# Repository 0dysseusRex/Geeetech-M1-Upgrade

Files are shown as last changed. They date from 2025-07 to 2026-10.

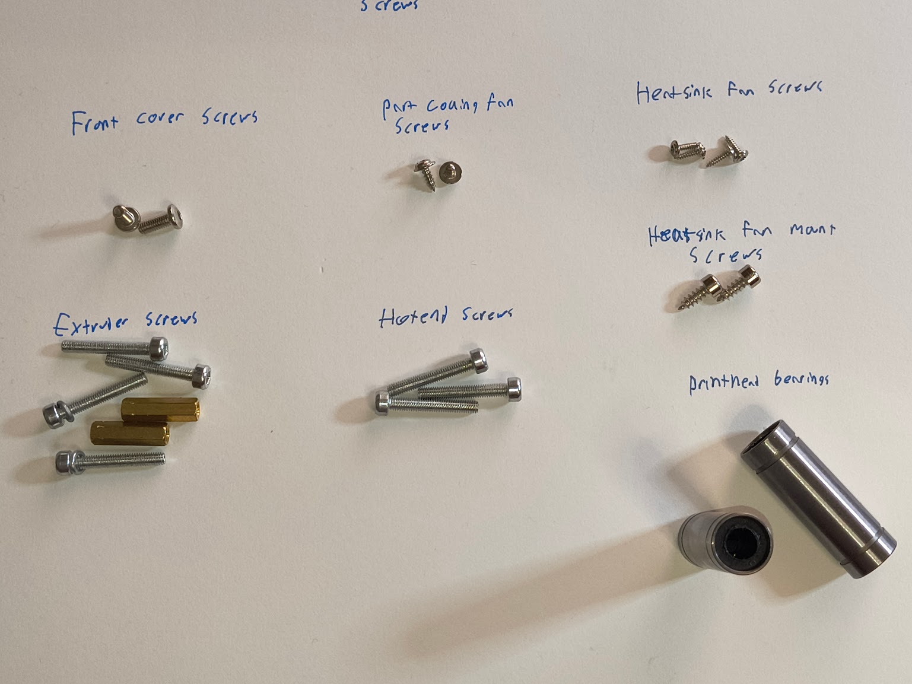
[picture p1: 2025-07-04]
Photos/Printhead Screws.jpg

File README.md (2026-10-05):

# 🛠️ Geeetech M1 Klipperization & Upgrade Project

Welcome to the build guide for transforming your humble Geeetech M1 into a lean, mean, Klipper-powered printing machine. This README outlines the upgrades, installation steps, and configuration notes for the project.

> 💡 Help me fund a 3D scanner so I can stop squeezing magic out of Polycam and a Razor phone.  
> 

---

<details>
<summary>📊 <strong>Project Completion Tracker</strong> — 40% Overall (Weighted by Major Milestones) — Click to expand</summary>

> **Note:** Project completion is calculated by assigning weights to major milestones as follows:
> - Printhead Re-design: 30%
> - Gantry Re-design: 30%
> - Electronics Mount: 20%
> - Software: 20%
> Weighted progress is shown below. All other tasks are tracked for transparency but do not affect the overall percentage.

### 🔧 Printhead Re-design — 90% (27% of total)
`█████████░`  
**✅ Completed:**  
- A1 Mini Hotend ✔️  
- Probe mounting location ✔️  
- Microprobe mount ✔️  
- Fan mounts ✔️  
- Cable guides ✔️  

**📝 To Do:**  
- Redesign bottom screw mounts to point forwards ❌  

---

### 🏗️ Gantry Re-design — 100% (30% of total)
`██████████`  
- Universal screw holes for custom MCU mounts ✔️  

---

### ⚙️ Electronics Mount — 60% (12% of total)
`██████░░░░`  
**✅ Completed:**  
- SKR Pico Mount ✔️  
**📝 To Do:**  
- Fly Lite 2.1 mount ❌  
- Knomi Mount ❌  
- E-stop Mount ❌  

The finished `STL Files/Electronics Mount/Pi Mount.stl` fits the previous Raspberry Pi Zero 2W host. It is not a verified Mellow Fly Lite 2.1 mount, so that STL is unchanged. The 60% figure above still counts that Pi mount.  

---

### 💻 Software — 0% (0% of total)
`░░░░░░░░░░`  
- Flash the Fly-bian 1.0 Simple-AF image on the Fly Lite 2.1 ❌  
- Draft `printer.cfg` written, not tested on the machine ❌  
- Run the Simple-AF install command in the installation section ❌  
- Test functionality ❌  

---

### 🔌 PSU Mount — 0%
`░░░░░░░░░░`  
- Not yet started ❌  

---

### 🧪 Testing — 0%
`░░░░░░░░░░`  
- Initial printer function tests ❌  
- PID tuning ❌  
- Input shaper graphs ❌  
- First test prints ❌  
- Speed tests ❌  
- Dial-in settings ❌  

---

### 🎬 Video Editing — 0%
`░░░░░░░░░░`  
- Not yet started ❌  

---

### 🌐 Publish & Go Live — 0%
`░░░░░░░░░░`  
- Awaiting completion ❌  

</details>

---

## 🧰 Project Overview

This upgrade journey includes:

- **Mainboard**: BTT SKR Pico (Klipper MCU)
- **Controller**: [Mellow Fly-Pi-lite2.1](https://mellow.klipper.cn/en/docs/ProductDoc/SBC/fly-lite/lite2.1/) (Fly Lite 2.1), the Klipper host
- **Host image**: [Fly-bian 1.0 Simple-AF](https://github.com/0dysseusRex/fly-bian/releases/tag/v1.0) — `Fly-bian-1.0_Fly-Lite-2.1_Simple-AF-0d21afe.img.xz`. This is unofficial Armbian/Debian from [fly-bian](https://github.com/0dysseusRex/fly-bian), not Mellow FlyOS
- **Power Supply**: Internal 100W unit for compact, clean power delivery
- **Custom Printhead Assembly**:
  - A1 Mini hotend for improved thermal performance  
  - Creality K1 extruder for smoother filament feed  
  - Microprobe sensor for reliable bed leveling
- **Streaming Camera**: Live monitoring via a USB camera on the Fly Lite

---

## 📦 Hardware List

| Component | Model/Description |
|---|---|
| Mainboard | BTT SKR Pico (Klipper MCU) |
| Controller | Mellow Fly-Pi-lite2.1 (Fly Lite 2.1) |
| Host image | Fly-bian 1.0 Simple-AF (`Fly-bian-1.0_Fly-Lite-2.1_Simple-AF-0d21afe.img.xz`) |
| Power Supply | Internal 100W |
| Hotend | A1 Mini |
| Extruder | Creality K1 |
| Bed Leveling | Microprobe sensor |
| Streaming Camera | USB (Fly Lite USB-A; no CSI connector on this host) |

---

## 🛠️ Installation Highlights

- **Controller (Fly Lite 2.1)**  
  - Flash only the Simple-AF card: [Fly-bian-1.0_Fly-Lite-2.1_Simple-AF-0d21afe.img.xz](https://github.com/0dysseusRex/fly-bian/releases/download/v1.0/Fly-bian-1.0_Fly-Lite-2.1_Simple-AF-0d21afe.img.xz) (SHA256 `3523ba04239469a7654b9d3b5ce8d07d9bf0d138a92ea3c833cd38d0f7c9e470`). Do not flash the Base or KIAUH image, FlyOS, or Raspberry Pi OS
  - Mellow specifies a MicroSD of 16–128 GB, speed class C10 or higher. The board has no eMMC
  - Before the first power-on, edit `fly-start.txt` on the `FLY-SETUP` volume (2.4 GHz Wi-Fi, locale, root password, sudo user). Steps: [Fly-bian Simple-AF how-to](https://github.com/0dysseusRex/fly-bian/blob/main/docs/howto-simpleaf.md)
  - Power the host from its own 5 V supply. Mellow says the Fly-Pi-lite2.1 must not be powered from the printer mainboard
  - Fit the IPEX antenna. Onboard Wi-Fi is 2.4 GHz only
  - After SSH login, `~/pellcorp` is already on the card. [Simple-AF for RPi](https://pellcorp.github.io/creality-wiki/rpi/) accepts a custom printer file as `--printer` (a GitHub file URL or a local path) and the probe as `--probe`. This machine is not one of the predefined printers, so there is no `--mount`. The draft [`printer.cfg`](printer.cfg) is that file. Run:

    ```
    ~/pellcorp/installer.sh --install --printer https://github.com/0dysseusRex/Geeetech-M1-Upgrade/blob/main/printer.cfg --probe microprobe
    ```

    The same line can be `INSTALL_CMD=` in `fly-start.txt` on the `FLY-SETUP` volume before the first boot. That is the hook in the [Fly-bian Simple-AF how-to](https://github.com/0dysseusRex/fly-bian/blob/main/docs/howto-simpleaf.md). The installer rewrites the GitHub URL to the raw file. `printer.cfg` is still a draft
  - The SKR Pico stays the MCU and still connects over USB. No Fly Lite GPIO pinout is added here
  - Wire power and comms with care—use ferrules for safety and reliability

- **Printhead Upgrade**  
  - Swap stock hotend for A1 Mini  
  - Mount Creality K1 extruder and calibrate steps/mm in Klipper  
  - Install Microprobe and configure mesh leveling

- **Power Integration**  
  - Mount internal 100W PSU  
  - Ensure tidy cable management and proper airflow

- **Camera Streaming**  
  - Connect a USB camera to a Fly Lite USB-A port. A CSI camera connector is not listed on the Fly-Pi-lite2.1
  - After Crowsnest is installed, `fly-crowsnest-add-cams` adds the camera. Fluidd and Mainsail are the web UIs on this image

---

## 🧠 Configuration Notes

- [`printer.cfg`](printer.cfg) is the Simple-AF `--printer` file for the SKR Pico MCU. Probe and mesh values are in its `-- microprobe.cfg` section so the installer keeps the SKR Pico probe pins. Simple-AF's own `START_PRINT` homes with `G28` on the mechanical endstops, then meshes. The Fly Lite 2.1 is the host. Its only documented Klipper GPIO is the KPPM pin, and this config does not load that pin. [`adxl345.cfg`](adxl345.cfg) is not part of that install; include it only while the USB accelerometer is plugged in
- Run PID tuning for hotend and bed  
- Enable Input Shaping with accelerometer (optional but recommended)  
- View the camera stream in Fluidd or Mainsail on the Fly Lite

---

## ✨ Acknowledgments

Big thanks to the Klipper community, BTT engineers, Pellcorp ([Simple AF](https://pellcorp.github.io/creality-wiki/)), Mellow for the [Fly-Pi-lite2.1](https://mellow.klipper.cn/en/docs/ProductDoc/SBC/fly-lite/lite2.1/), the [Fly-bian](https://github.com/0dysseusRex/fly-bian) image, and [adamrodgers/geeetech-m1s-klipper](https://github.com/adamrodgers/geeetech-m1s-klipper) for the stock M1S X/Y/Z motor steps, travel, homing direction, and cartesian kinematics in `printer.cfg`. That project keeps the original M1S board, so only those motion numbers were used here. And thanks to all the DIYers who turn retro machines into futuristic wonders.

---

> 🧠 Print smarter, not harder.  
> 🤖 Yes, this README was AI-generated—but only as a launchpad. BOM coming soon.

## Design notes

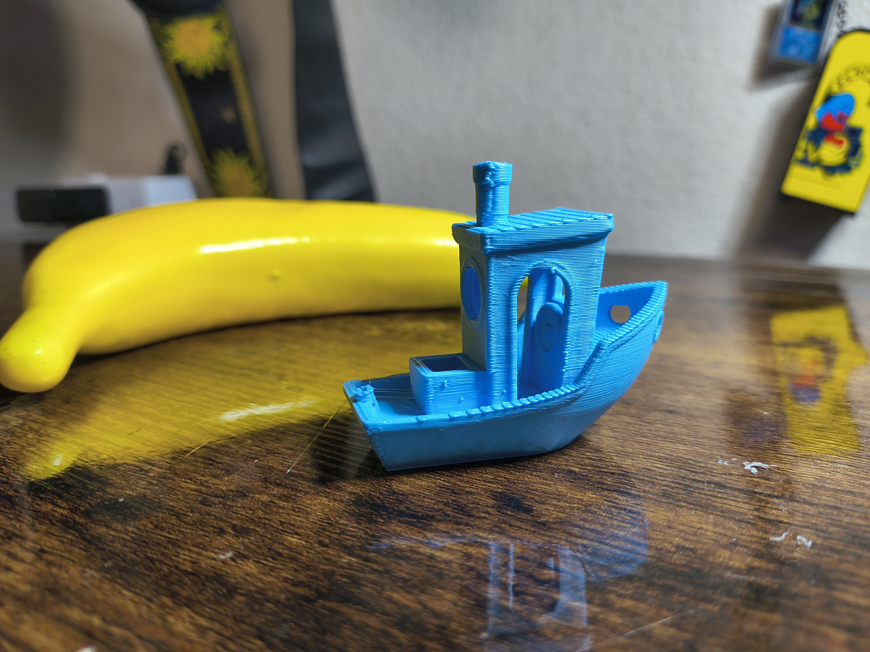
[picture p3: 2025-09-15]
Photos/IMG_20250629_211448033_HDR.jpg

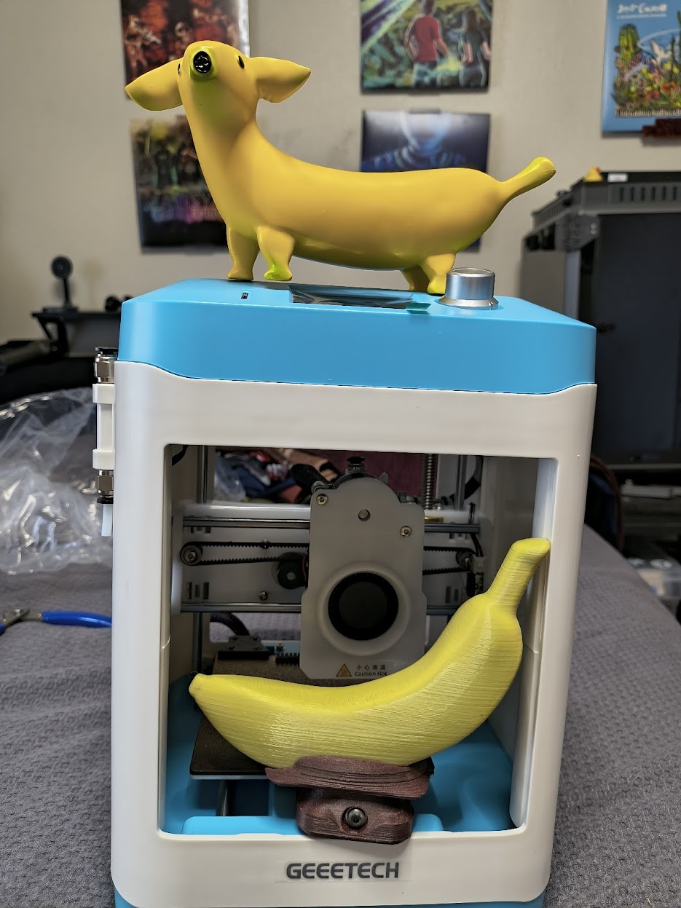
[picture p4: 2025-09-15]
Photos/IMG_20250625_182029436_HDR.jpg

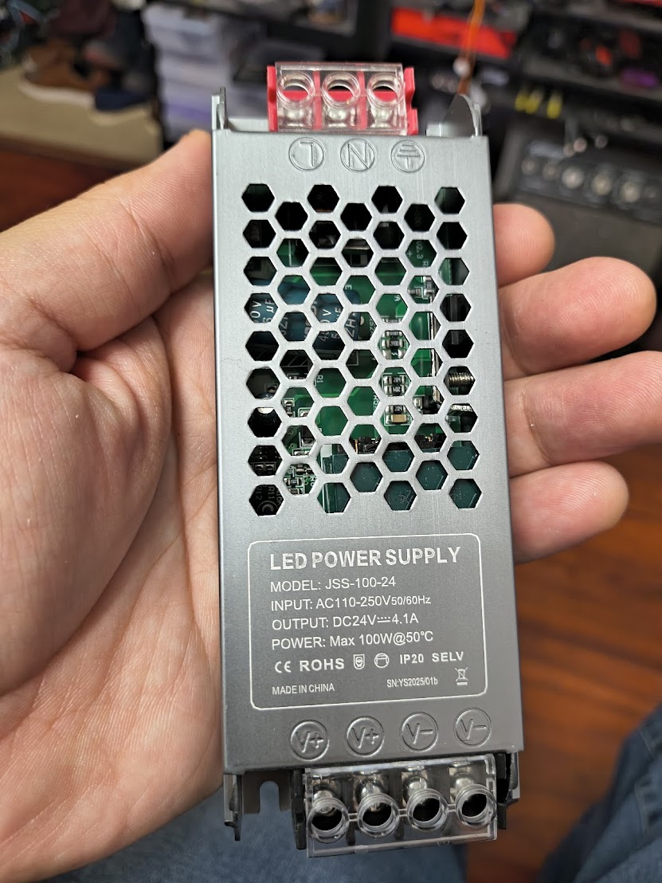
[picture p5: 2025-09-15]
Photos/IMG_20250629_103606269_HDR.jpg

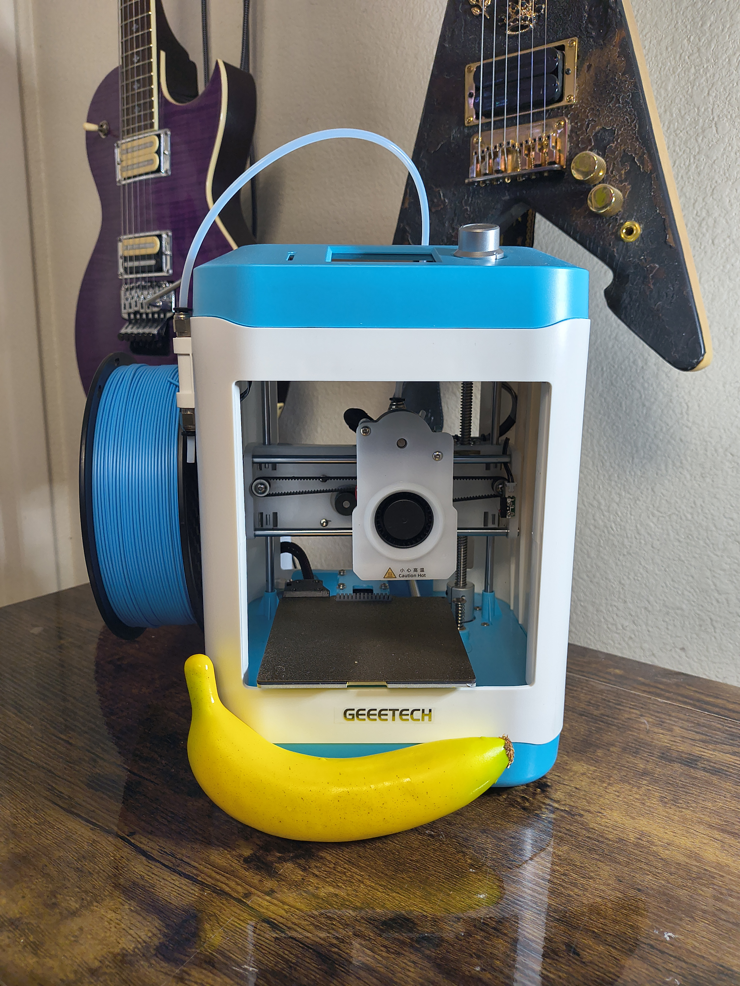
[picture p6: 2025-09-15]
Photos/IMG_20250629_200729336_HDR.jpg

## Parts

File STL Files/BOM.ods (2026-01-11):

Printhead BOM
# | Item | Cost | Link
9 | M3 Voron Heat Set Insert | $9.99 | https://www.amazon.com/dp/B0CDH36ZMX
2 | M2.5 Heat Set Insert | $8.99 | https://www.amazon.com/dp/B0CS6YVJYD
2 | 8X2mm magnets | $6.99 | https://www.amazon.com/dp/B09TVXL3DZ
2 | M4x20 Socket Head Screws | $8.99 | https://www.amazon.com/dp/B0DCVVSGW2

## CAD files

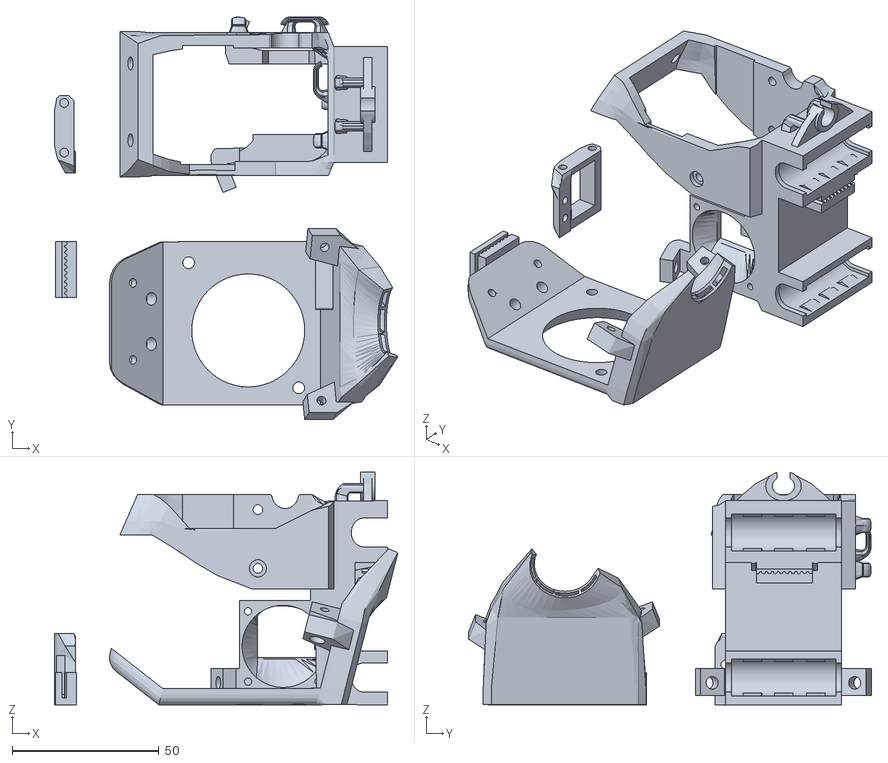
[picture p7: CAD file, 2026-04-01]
STL Files/Printhead/Full Toolhead.stl
117.1 x 137.4 x 79.3

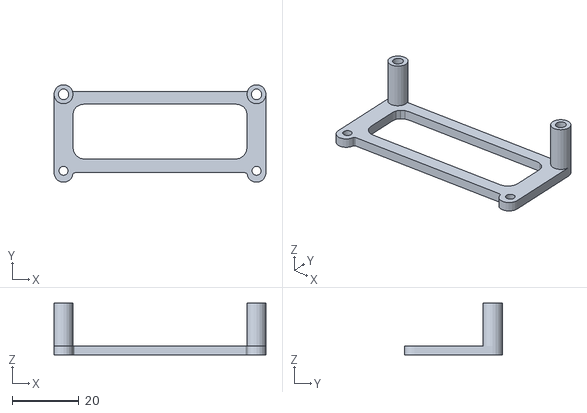
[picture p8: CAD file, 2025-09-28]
STL Files/Electronics Mount/Pi Mount.stl
63.7 x 29.3 x 15.6

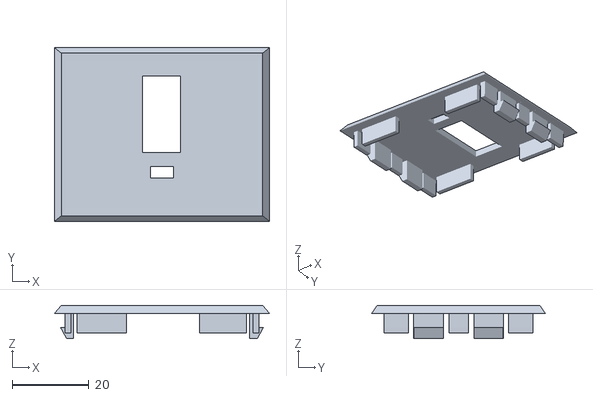
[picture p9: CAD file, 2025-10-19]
STL Files/Knomi/Knomi Mount Base.stl
56.2 x 45.4 x 8.70

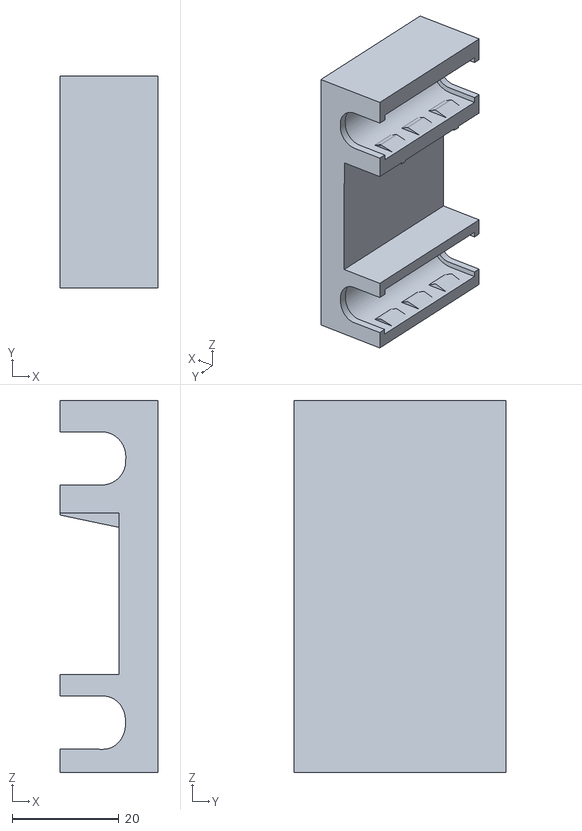
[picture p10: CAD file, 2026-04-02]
STL Files/Printhead/Universal Carriage.stl
18.4 x 39.6 x 69.6

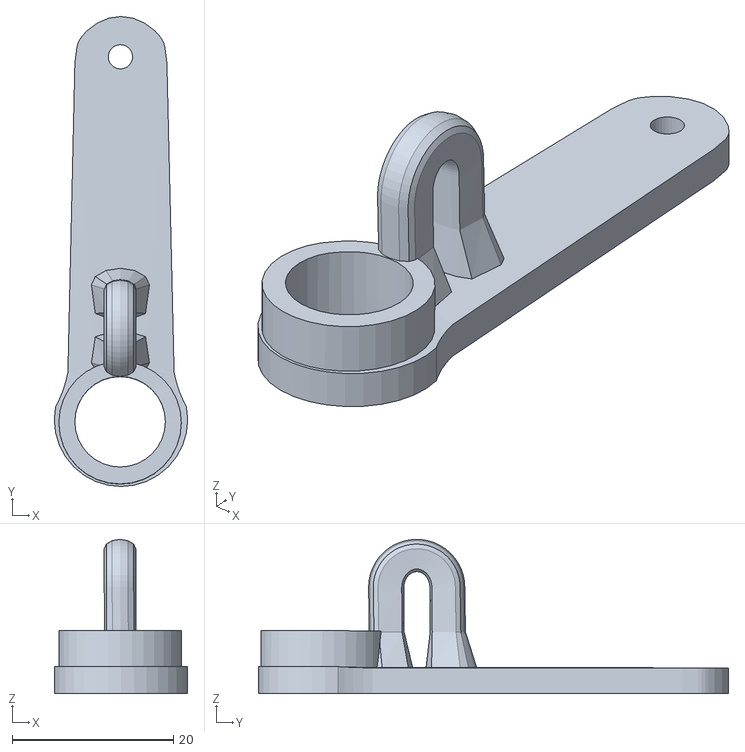
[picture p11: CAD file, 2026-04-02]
STL Files/X Gantry/Cable Guide.stl
16.5 x 58.2 x 19.1

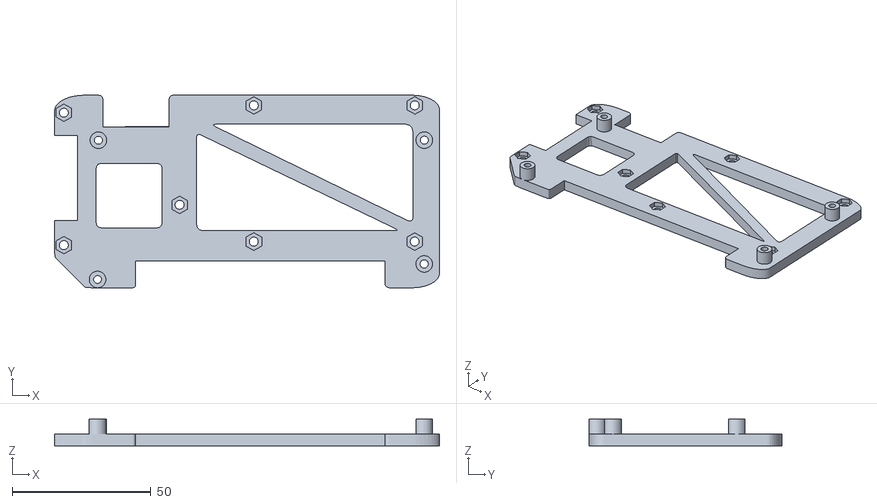
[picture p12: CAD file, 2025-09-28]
STL Files/Electronics Mount/Electronics Mount.stl
138.7 x 69.4 x 9.72

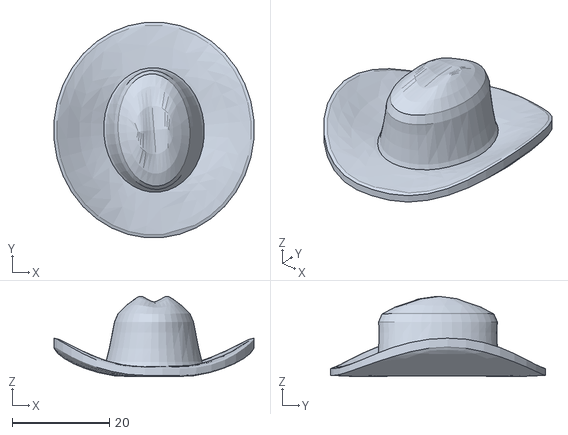
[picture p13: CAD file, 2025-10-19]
STL Files/Knomi/Cowboy Hat.stl
41.2 x 44.3 x 16.5

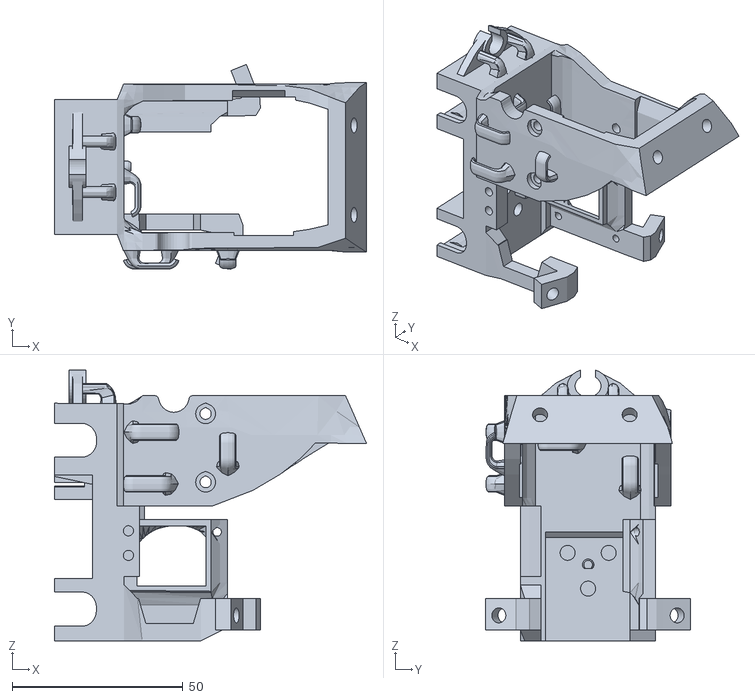
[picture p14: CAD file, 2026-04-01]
STL Files/Printhead/Toolhead.stl
91.3 x 60.0 x 79.3

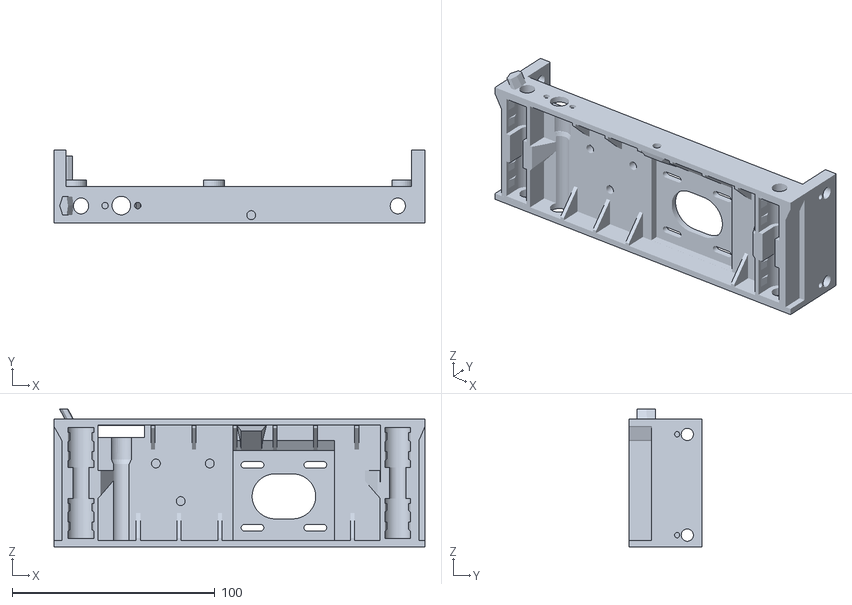
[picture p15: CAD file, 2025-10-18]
STL Files/X Gantry/Gantry.stl
183.0 x 36.0 x 68.0

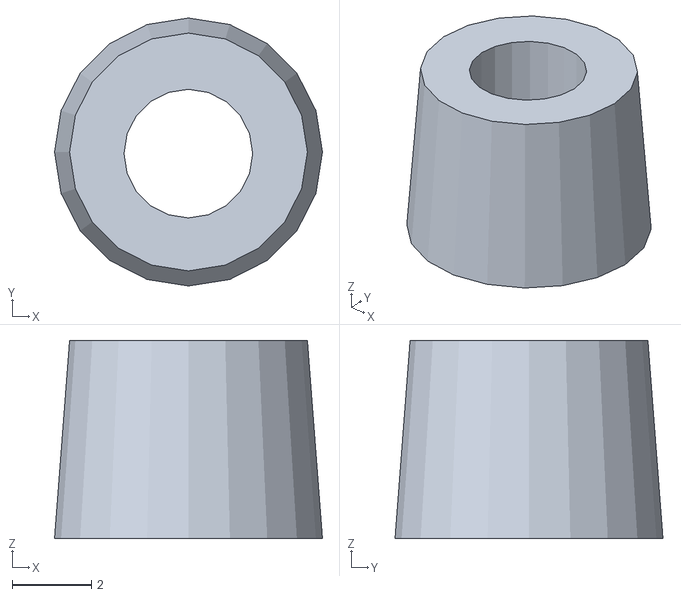
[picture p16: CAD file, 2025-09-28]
STL Files/Electronics Mount/Spacer.stl
6.76 x 6.76 x 5.00

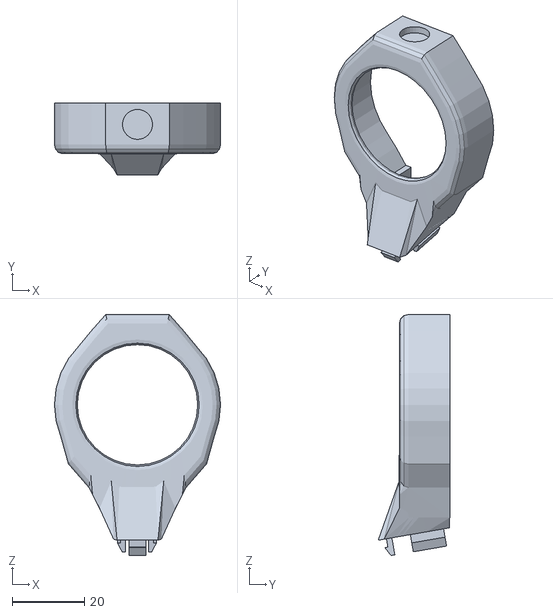
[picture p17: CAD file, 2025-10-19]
STL Files/Knomi/Knomi Case.stl
46.0 x 19.8 x 66.7

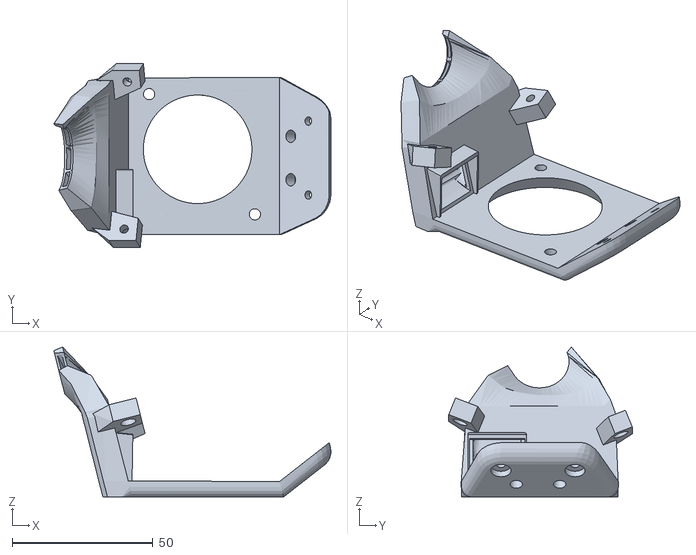
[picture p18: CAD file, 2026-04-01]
STL Files/Printhead/Cover Test.stl
98.3 x 65.1 x 53.2

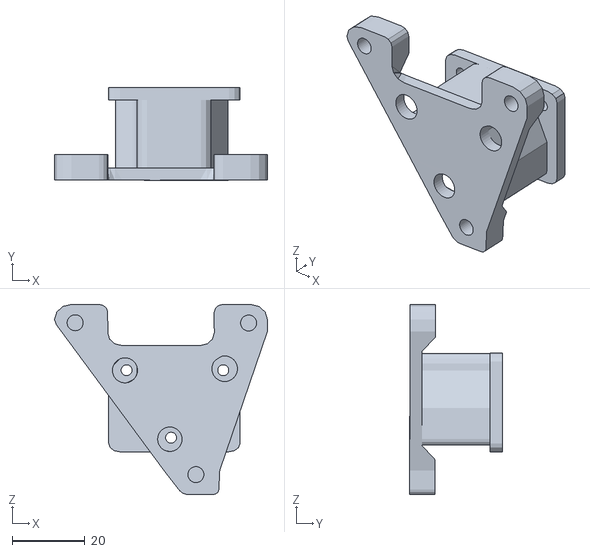
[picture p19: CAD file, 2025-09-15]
STL Files/X Gantry/MCU Mount.stl
58.6 x 25.5 x 52.3

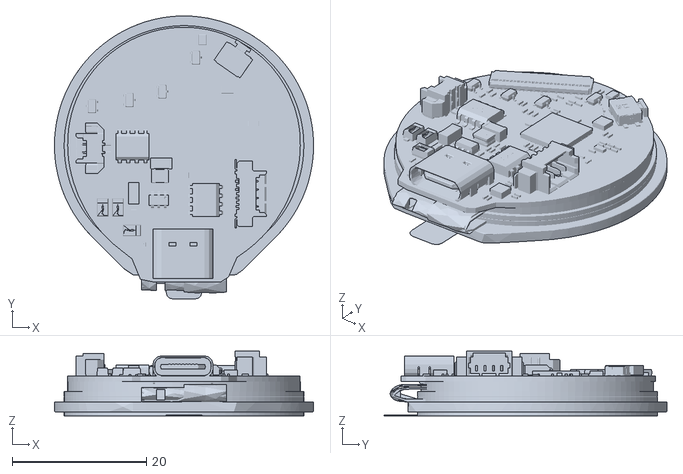
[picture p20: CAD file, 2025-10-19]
STL Files/Knomi/KNOMI 2 Mockup.stl
38.5 x 42.1 x 9.63

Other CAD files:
STL Files/Knomi/Knomi Lid.stl
STL Files/Printhead/Belt Clip.stl
STL Files/Printhead/Microprobe Mount.stl

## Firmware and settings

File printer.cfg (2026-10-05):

# Geeetech M1 — Simple-AF printer definition. Not calibrated. Do not heat
# until the DRAFT sensor types below are replaced with the real ones.
#
# Host: Mellow Fly-Pi-lite2.1 (Fly Lite 2.1) on Fly-bian Simple-AF.
# The Lite is a Klipper host, not a stepper board. Mellow documents one
# host GPIO for Klipper, and only for a KPPM module:
#   host:gpiochip1/gpio8
# https://mellow.klipper.cn/en/docs/ProductDoc/SBC/fly-lite/lite2.1/advanced/kppm/
# This printer config does not load that pin. Do not copy a Fly-Pi 40-pin
# map onto the Lite; Mellow does not publish one for this board.
# https://github.com/0dysseusRex/fly-bian/blob/main/docs/klipper-pins-and-macros.md
#
# Motion MCU: BTT SKR Pico, still the mainboard in this repo. Pin names
# below are the SKR Pico connectors from Klipper's generic config:
# https://github.com/Klipper3d/klipper/blob/master/config/generic-bigtreetech-skr-pico-v1.0.cfg
# Compile that MCU for the RP2040 with USB. "make flash" does not work;
# copy out/klipper.uf2 to the board in boot mode.
#
# Toolhead in this repo: A1 Mini hotend, Creality K1 extruder, BTT
# Microprobe, fan mounts. Motors, endstops, and the first home are the
# original M1. The Microprobe is not the homing endstop.
#
# X/Y/Z rotation distances, travel, and homing direction are from the stock
# M1S Marlin dump (M92/M201/M203/M211/M119). The M1S is the M1 plus Wi-Fi;
# the mechanics match. Source:
# https://github.com/adamrodgers/geeetech-m1s-klipper
# Their MCU pins are for the stock APM32 board and are not used here.
#
# Advertised volume is 100 x 110 x 100 mm. Stock M211 travel is
# X 0..115, Y 0..114, Z 0..95. Nozzle max 230 C, bed max 60 C.
#
# Simple-AF wants one file. Lines that start with "-- name.cfg" are
# sections it copies into that file. It rejects [include] and SAVE_CONFIG.
# https://pellcorp.github.io/creality-wiki/rpi_printer_definitions/
# Comment lines are dropped on install. The values are not.
#
# Do not add START_PRINT or END_PRINT here. Simple-AF start_end.cfg
# already defines them. Its G28 uses the mechanical endstops below.
# The Microprobe is only for the mesh that start sequence runs after G28.
#
# The Mellow ADXL345 stays out of this file. See adxl345.cfg. Include
# that file only while input shaping is running.
#
# Lines marked DRAFT are placeholders. This repo and the sources above
# do not give those values.

-- printer.cfg
[mcu]
# DRAFT: replace with the SKR Pico path from `ls /dev/serial/by-id/`.
# Reject usb-1a86_USB_Serial (the Lite's Type-C UART) and anything
# with katapult in the name.
serial: /dev/serial/by-id/usb-Klipper_rp2040_DRAFT_SKR_PICO-if00

[printer]
# Cartesian bed slinger: the bed moves in Y. Confirmed on the M1S dump.
kinematics: cartesian
# Stock M203: X 200, Y 200. The wiki's 250 mm/s claim is higher than this.
max_velocity: 200
# Stock M201: X 3000, Y 3000.
max_accel: 3000
# Stock M203 Z.
max_z_velocity: 25
# Stock M201 Z.
max_z_accel: 500

[stepper_x]
step_pin: gpio11
# DRAFT: Pico DIR polarity is not the stock board's. Stock homes to X max.
# If X moves away from the switch, remove or add "!".
dir_pin: !gpio10
enable_pin: !gpio12
microsteps: 16
# Stock M92 X80 at 16 microsteps: 200 * 16 / 80 = 40 (GT2 20-tooth).
rotation_distance: 40
# SKR Pico X endstop connector. DRAFT pull-up polarity.
endstop_pin: ^gpio4
# Stock M119: x_max. M211 max is 115. Homes on the switch, not the probe.
position_endstop: 115
position_max: 115
position_min: 0
homing_speed: 25
homing_positive_dir: true

[tmc2209 stepper_x]
uart_pin: gpio9
tx_pin: gpio8
uart_address: 0
# Stock M906 X800, stealthChop (M569).
run_current: 0.800
stealthchop_threshold: 999999

[stepper_y]
step_pin: gpio6
# DRAFT: Pico DIR polarity. Stock Y homes toward the back (min) endstop.
# Flip "!" if it homes the wrong way.
dir_pin: !gpio5
enable_pin: !gpio7
microsteps: 16
# Stock M92 Y80 at 16 microsteps.
rotation_distance: 40
# SKR Pico Y endstop connector. DRAFT pull-up polarity.
endstop_pin: ^gpio3
# Stock M119: y_min. M211 max is 114. G28 ends at Y0.
position_endstop: 0
position_max: 114
position_min: 0
homing_speed: 25

[tmc2209 stepper_y]
uart_pin: gpio9
tx_pin: gpio8
uart_address: 2
# Stock M906 Y800, stealthChop.
run_current: 0.800
stealthchop_threshold: 999999

[stepper_z]
step_pin: gpio19
# DRAFT: Pico DIR polarity. Stock Z homes toward the frame switch (min).
dir_pin: gpio28
enable_pin: !gpio2
microsteps: 16
# Stock M92 Z830 at 16 microsteps: 200 * 16 / 830 = 3.8554.
# Not a standard 4 mm or 8 mm lead. Confirm on the leadscrew.
rotation_distance: 3.8554
# Mechanical frame switch. Do not change this to probe:z_virtual_endstop.
endstop_pin: ^gpio25
# The M1S config used -0.8 after a paper test on the stock nozzle.
# This toolhead is different, so 0 is only a starting point.
position_endstop: 0
# Stock M211 Z max. Their config allows -2 for switch clearance.
position_min: -2
position_max: 95
homing_speed: 10
second_homing_speed: 2
homing_retract_dist: 3

[tmc2209 stepper_z]
uart_pin: gpio9
tx_pin: gpio8
uart_address: 1
# DRAFT PLACEHOLDER. Stock Z is an A4988, so M906 has no Z current.
run_current: 0.580
stealthchop_threshold: 999999

[extruder]
step_pin: gpio14
# DRAFT: sample polarity. Creality K1 direction is not recorded here.
dir_pin: !gpio13
enable_pin: !gpio15
microsteps: 16
# DRAFT PLACEHOLDER. Creality K1 rotation_distance is not in this repo.
rotation_distance: 33.500
nozzle_diameter: 0.400
filament_diameter: 1.750
heater_pin: gpio23
# DRAFT PLACEHOLDER. A1 Mini thermistor type is not identified.
# Do not heat the hotend until this is replaced.
sensor_type: EPCOS 100K B57560G104F
sensor_pin: gpio27
# watermark avoids invented PID gains. Run PID_CALIBRATE before printing.
control: watermark
min_temp: 0
# Wiki maximum extruder temperature.
max_temp: 230

[tmc2209 extruder]
uart_pin: gpio9
tx_pin: gpio8
uart_address: 3
# DRAFT PLACEHOLDER. Not a measured K1 extruder current.
run_current: 0.650
stealthchop_threshold: 999999

[heater_bed]
heater_pin: gpio21
# DRAFT PLACEHOLDER. The stock M1 bed thermistor is not identified.
# Do not heat the bed until this is replaced.
sensor_type: ATC Semitec 104GT-2
sensor_pin: gpio26
control: watermark
min_temp: 0
# Wiki maximum hot-bed temperature.
max_temp: 60

# DRAFT: which toolhead fan lands on which SKR Pico fan pin is not documented.
# gpio17 and gpio18 are the sample part-cooling and hotend-fan connectors.
[fan]
pin: gpio17

[heater_fan hotend_fan]
pin: gpio18
heater: extruder
heater_temp: 50.0

-- microprobe.cfg
# BTT MicroProbe on the SKR Pico probe connector from the generic file
# (sensor gpio22, control gpio29). DRAFT: this repo does not show that wiring.
# V1 triggers high (^). V2 triggers low (^!). Version is not recorded here.
# Manual: https://lemontron.com/assets/downloads/biqu-microprobe-manual.pdf
# Simple-AF copies its own microprobe.cfg, then patches these keys over it.
[output_pin probe_enable]
pin: gpio29
value: 0

[probe]
pin: ^gpio22
deactivate_on_each_sample: False
# DRAFT PLACEHOLDER. Mount offsets are not measured.
x_offset: 0.0
y_offset: 0.0
z_offset: 0.0
speed: 5.0
activate_gcode:
    SET_PIN PIN=probe_enable VALUE=1
    G4 P500
deactivate_gcode:
    SET_PIN PIN=probe_enable VALUE=0

[bed_mesh]
speed: 50
# DRAFT PLACEHOLDER.
horizontal_move_z: 5
# DRAFT inset inside the stock 115 x 114 travel. Probe offset is still 0.
# The stock nozzle mesh covered about 10,10 to 95,100. Move these once the
# Microprobe offset is measured.
mesh_min: 10, 10
mesh_max: 90, 100
probe_count: 3, 3
algorithm: bicubic

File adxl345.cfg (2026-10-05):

# Mellow Fly-ADXL345-USB. Include this only while the board is plugged in.
# Do not put [include adxl345.cfg] in the printer.cfg that Simple-AF installs
# from. That installer rejects includes. After install, add the include to
# the installed printer.cfg only for an input-shaping run, then remove it.
# Klipper will not start if this file is included and the USB MCU is missing.
#
# These pins are the RP2040 on the USB accelerometer, not Fly Lite SoC pins.
# The Lite 2.1 cannot drive a bare SPI/I2C ADXL345:
# https://mellow.klipper.cn/en/docs/ProductDoc/SBC/fly-lite/lite2.1/advanced/adxl/
# Pin names from Mellow's Fly-ADXL345-USB sample:
# https://mellow-3d.github.io/fly_adxl345_usb_klipper_config.html

[mcu adxl]
# DRAFT: replace with `ls /dev/serial/by-id/` while the board is plugged in.
serial: /dev/serial/by-id/usb-Klipper_rp2040_DRAFT_ADXL345-if00

[adxl345]
cs_pin: adxl:gpio9
spi_software_sclk_pin: adxl:gpio10
spi_software_mosi_pin: adxl:gpio11
spi_software_miso_pin: adxl:gpio12
# axes_map is omitted. Mount orientation on this toolhead is not recorded.
# Klipper's default is x, y, z. Check it with ACCELEROMETER_QUERY before
# trusting SHAPER_CALIBRATE.

[resonance_tester]
accel_chip: adxl345
# DRAFT PLACEHOLDER. Mellow's sample point (150, 150, 20) is outside this
# printer. 57.5, 57 is the middle of the stock M211 travel (115 x 114).
probe_points:
    57.5, 57, 20

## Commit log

2025-07-07 Universal Carriage
    Remix with your preferred hotend/extruder solution.
    [Universal Carraige.stl]
2025-07-14 Added experimental toolhead
    [Belt Clip.stl, Cover Test.stl, Microprobe Mount Test.stl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]
2025-07-19 Update Toolhead Test.stl
    [Toolhead Test.stl]
2025-07-22 Updated carriage
    [Belt Holder.stl, Carriage.stl, Cover Test.stl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]
2025-07-27 Added 3D Scan of the X-Gantry
2025-07-27 Added 3D Scan of the Carriage
2025-07-27 Uploaded 3D scan of top for making electronics mount
2025-09-07 Create X Gantry Generic.stl
    [X Gantry Generic.stl]
2025-09-12 Updated gantry and added mcu mount and cable guide
    [Cable Guide.stl, MCU Mount.stl, X Gantry Generic.stl]
2025-09-15 Gantry finalized
    [MCU Mount.stl, X Gantry Generic.stl]
2025-09-15 BOM
    Still need to add more items
    [BOM.ods]
2025-09-28 Electronics Mount
    Mount plus spacers
    [Electronics Mount.stl, Spacer 1.stl, Spacer 2.stl]
2025-09-28 Update Electronics Mount.stl
    Fixed hole placement and made manifold
    [Electronics Mount.stl]
2025-09-28 Pi Mount
    Added Pi Mount and fixed the Spacer
    [Pi Mount.stl, Spacer 2.stl, Spacer.stl]
2025-10-15 Update X Gantry Generic.stl
    Fixed some spacings
    [X Gantry Generic.stl]
2025-10-16 Update X Gantry Generic.stl
    'nother update
    [X Gantry Generic.stl]
2025-10-18 Images + New Cable Guide
    [Belt Holder.stl, Cable Guide.stl, Gantry.stl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]
2025-10-19 Knomi MOunt
    [Cowboy Hat.stl, KNOMI 2 Mockup.stl, Knomi Case.stl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]
2026-04-01 Version 3
    Fixed some fitment issues. Changed blower geometry. Changed screw locations.
    [Belt Clip.stl, Carriage.stl, Cover Test.stl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]
2026-04-02 STL Updates
    [Cable Guide.stl, Universal Carraige.stl, Universal Carriage.stl]
2026-10-05 Specify the Fly Lite 2.1 and Fly-bian Simple-AF image
    Replace the Raspberry Pi Zero 2W host with the Mellow Fly-Pi-lite2.1 running the published Fly-bian 1.0 Simple-AF image. The SKR Pico stays the Klipper MCU.
2026-10-05 Add a draft Klipper config for the Fly Lite host and SKR Pico
    The Fly Lite 2.1 stays the host. Motion pins are the SKR Pico sample map. The Mellow ADXL345 USB config is a separate file and is not included, so startup does not require it.
    [adxl345.cfg, printer.cfg]
2026-10-05 Point the README at the draft printer.cfg
    The draft is untested. The ADXL345 include stays commented out.
2026-10-05 Use stock M1S motion numbers for X, Y, and Z
    Rotation distance, travel, homing direction, and axis limits come from the published M1S Marlin dump. SKR Pico pins stay. The stock board pin map is not copied.
    [adxl345.cfg, printer.cfg]
2026-10-05 Credit the M1S Klipper config for the motion numbers
    The stock Marlin dump in adamrodgers/geeetech-m1s-klipper supplied the X/Y/Z steps, travel, and homing direction.
2026-10-05 Note the Simple-AF install command for the custom printer.cfg
2026-10-05 Credit the M1S config for motor and kinematics numbers
2026-10-05 Put the Simple-AF printer definition on main
    [adxl345.cfg, printer.cfg]
